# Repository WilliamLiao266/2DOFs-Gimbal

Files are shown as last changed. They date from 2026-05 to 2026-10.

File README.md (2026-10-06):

# 2DOFs Gimbal

基于 ESP32、SimpleFOC、双无刷电机和双 AS5600 磁编码器实现的两自由度云台。项目包含 Yaw / Pitch 双轴闭环控制固件、浏览器 PID 调参面板、结构模型以及硬件参考资料，可用于云台结构验证、FOC 调试和串口控制实验。

> 当前版本仍处于硬件调试阶段。上电前请先确认机械限位、供电电压、电机极对数与引脚配置，并确保急停或断电手段随时可用。

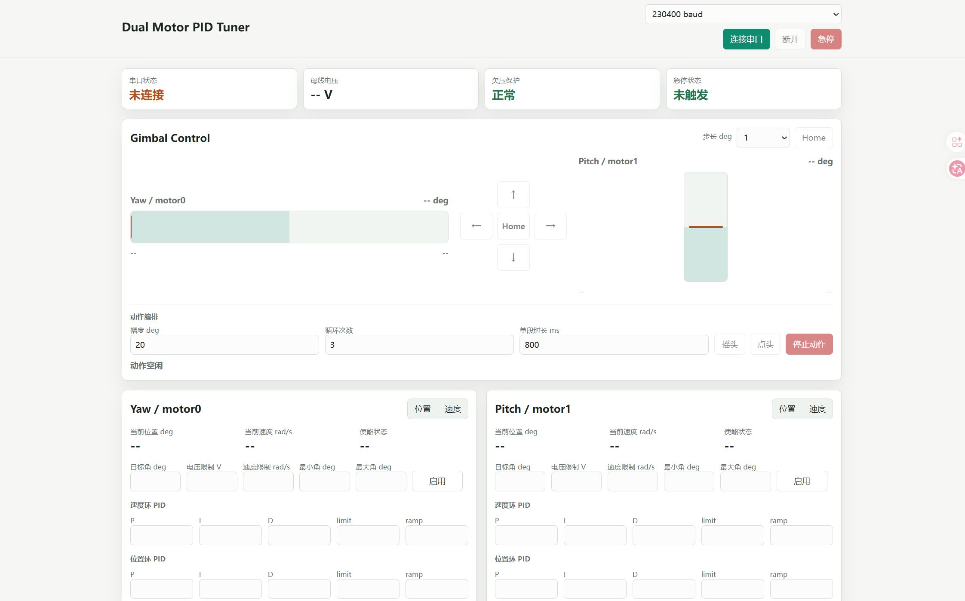
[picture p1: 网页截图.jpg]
双轴云台 Web 调试界面


## 功能特性

- 双轴 FOC：`motor0` 控制 Yaw，`motor1` 控制 Pitch
- 支持位置模式与速度模式，并可分别启用或关闭两个电机
- 在浏览器中通过 Web Serial 实时读取角度、速度、母线电压和运行状态
- 在线修改速度环 / 位置环 PID、输出限制、速度限制和角度范围
- 提供云台方向控制、步进点动、Home 和急停操作
- 具备 11.1 V 欠压保护、目标角限幅和串口急停
- 附带 SolidWorks / STEP 结构模型、电机尺寸图、驱动板及编码器资料

## 系统组成

| 模块 | 当前配置 |
| --- | --- |
| 主控 | LOLIN32 Lite（ESP32） |
| 控制框架 | Arduino + SimpleFOC 2.2.1 |
| 驱动方式 | 双路 3PWM 无刷电机驱动 |
| 位置反馈 | 2 × AS5600，通过两路独立 I²C 总线读取 |
| 控制轴 | Yaw（motor0）/ Pitch（motor1） |
| Yaw 电机 | GB1806 云台无刷电机 |
| Pitch 电机 | GB1105 云台无刷电机 |
| 调参方式 | Web Serial，230400 baud |
| 开发环境 | PlatformIO |

### 电机型号与购买链接

| 控制轴 | 电机型号 | 购买链接 |
| --- | --- | --- |
| Yaw / motor0 | **GB1806 云台无刷电机** | [淘宝购买](https://item.taobao.com/item.htm?id=809646293074) |
| Pitch / motor1 | **GB1105 云台无刷电机** | [淘宝购买](https://item.taobao.com/item.htm?id=650837545641) |

> 商品页面的价格、库存和可选配置可能发生变化，下单前请再次确认电机型号、绕组、编码器选项及安装尺寸。

### 当前固件引脚

| 功能 | motor0 / Yaw | motor1 / Pitch |
| --- | ---: | ---: |
| 电机极对数 | 7 | 6 |
| 3PWM | GPIO 32 / 33 / 25 | GPIO 26 / 27 / 14 |
| 驱动使能 | GPIO 12（两轴共用） | GPIO 12（两轴共用） |
| AS5600 SDA / SCL | GPIO 19 / 18 | GPIO 23 / 5 |

母线电压由 GPIO 13 采样，源码使用 `8.5` 倍分压换算，并在电压低于 `11.1 V` 时关闭电机。若硬件版本或分压电阻不同，请先修改 [`src/main.cpp`](./src/main.cpp) 中的配置。

## 快速开始

### 1. 准备环境

- 安装 [Visual Studio Code](https://code.visualstudio.com/) 与 [PlatformIO IDE](https://platformio.org/install/ide?install=vscode)，或单独安装 PlatformIO Core
- 使用支持 Web Serial 的桌面版 Chrome 或 Edge
- 接线并检查两个电机、两个 AS5600、驱动板、公共地和电源

### 2. 获取并编译固件

```bash
git clone https://github.com/WilliamLiao266/2DOFs-Gimbal.git
cd 2DOFs-Gimbal
pio run
```

### 3. 烧录与查看串口

连接 ESP32 后执行：

```bash
pio run --target upload
pio device monitor --baud 230400
```

如果自动识别不到串口，可在 `platformio.ini` 中设置 `upload_port` 和 `monitor_port`，或在命令中通过 `--upload-port` / `--port` 指定。

### 4. 打开 Web 调参面板

先退出串口监视器，避免串口被占用。然后在仓库根目录启动本地静态服务器：

```bash
python -m http.server 8000 --directory tools
```

使用 Chrome 或 Edge 打开 <http://localhost:8000/pid_tuner.html>，保持波特率为 `230400`，点击“连接串口”并选择 ESP32 对应端口。

> 浏览器串口和 PlatformIO 串口监视器不能同时占用同一个端口。调参时建议先设置较小的电压 / 速度限制，并逐轴启用。

## 默认控制参数

| 参数 | Yaw / motor0 | Pitch / motor1 |
| --- | ---: | ---: |
| 初始目标角 | 90° | 135° |
| 角度范围 | 0° ～ 180° | 85° ～ 165° |
| 电压限制 | 12.087 V | 12.070 V |
| 速度限制 | 5 rad/s | 60 rad/s |
| 速度环 P / I / D | 0.10 / 0.80 / 0 | 0.25 / 1.50 / 0 |
| 位置环 P / I / D | 3.0 / 0 / 0 | 4.0 / 0 / 0 |

以上是当前样机参数，不应直接视为其他电机或机械结构的安全参数。更换电机、供电、负载或减速结构后，请重新辨识方向、极对数、零位和 PID。

## 串口协议

命令使用英文逗号分隔，并以换行符结束。电机索引 `0` 为 Yaw，`1` 为 Pitch。

| 操作 | 示例 |
| --- | --- |
| 切换模式 | `MODE,0,angle` / `MODE,1,velocity` |
| 设置目标 | `TARGET,0,90` |
| 修改 PID | `PID,0,vel,P,0.1` |
| 修改电压限制 | `LIMIT,0,voltage,6` |
| 修改速度限制 | `LIMIT,1,velocity,10` |
| 修改角度范围 | `LIMIT,1,angleMin,85` |
| 启用 / 关闭电机 | `ENABLE,0,1` / `ENABLE,0,0` |
| 两轴急停 | `ESTOP` |

固件以 JSON Lines 形式返回遥测、确认和错误消息，Web 调参面板会自动解析这些数据。

## 调参记录

下图记录了两轮 PID 调试结果。第二轮加入了更明确的角度范围和两轴差异化参数，当前源码中的默认值以最新一轮结果为基础。

| 2026-05-21 初步调参 | 2026-05-22 迭代调参 |
| --- | --- |
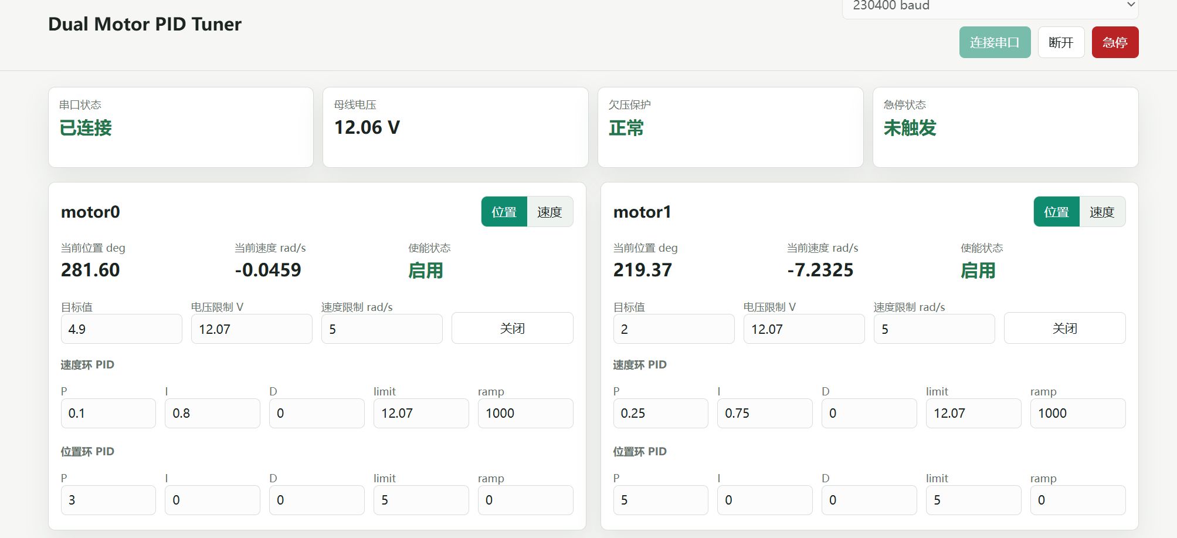
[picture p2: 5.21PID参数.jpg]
2026-05-21 PID 参数
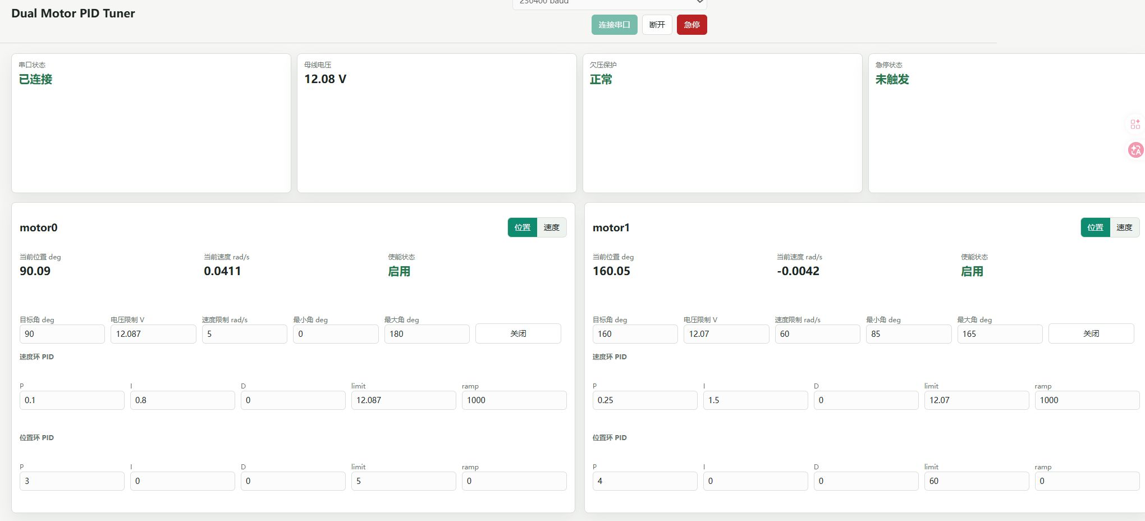
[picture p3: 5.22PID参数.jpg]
2026-05-22 PID 参数
|  |  |

## 项目结构

```text
.
├── src/main.cpp             # ESP32 双轴 FOC 固件与串口协议
├── tools/pid_tuner.html     # Web Serial 调参与云台控制面板
├── Motor_config/            # 电机资料图片
├── hardware_resource/       # 驱动板、编码器和安装尺寸资料
├── model/                   # SolidWorks 装配体、零件与 STEP 模型
├── platformio.ini           # PlatformIO 工程配置
├── 网页截图.jpg
├── 5.21PID参数.jpg
└── 5.22PID参数.jpg
```

## 安全提示

- 首次启动时拆除易碰撞负载，固定云台底座，并预留断电空间。
- `initFOC()` 会执行传感器与电机对齐；校准期间电机可能转动。
- GPIO 12 为两路驱动共用使能，请确认硬件连接与启动电平符合当前驱动板。
- 电压限制是控制器输出限制，不等同于电源或电机的额定安全电压。
- 调整角度上下限前先确认编码器方向和机械零位，防止撞击结构限位。
- 急停后需发送新的 `ENABLE` 命令才能恢复对应电机，请先排除故障原因。

## 许可证

本仓库目前尚未添加开源许可证。在许可证明确前，默认保留全部权利；如计划开放复用或接受外部贡献，请在发布时补充合适的 `LICENSE` 文件。

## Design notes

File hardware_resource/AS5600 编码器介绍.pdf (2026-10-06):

### AS5600 编码器板文档/AS5600 Encoder Board Document

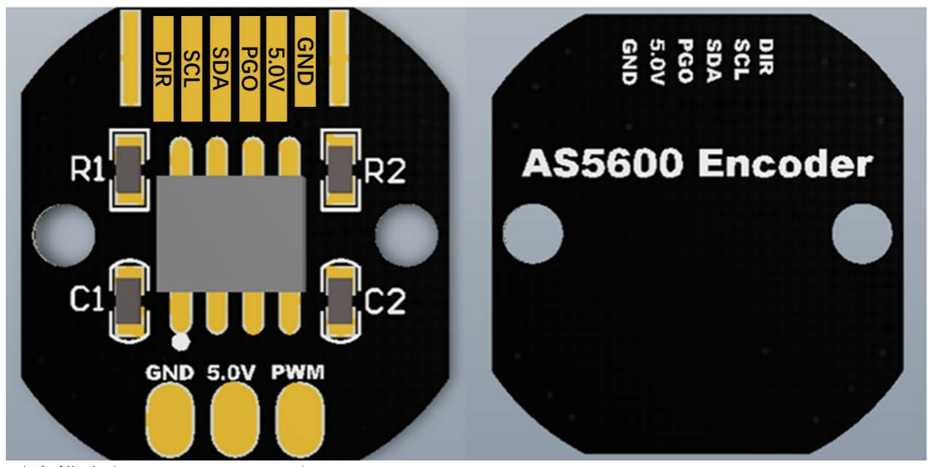
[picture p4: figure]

引脚描述(Pin Description)
名称(NAME) | 类型(TYPE) | 说明(Description)
GND | 电源(Supply) | 电源地(Ground)
5.0V | 电源(Supply) | 5V 直流电源(supply in 5V)
PWM | 输出(Output) | 460Hz PWM 输出(460Hz PWM Output)
PGO | 输入(Input） | 编程引脚(Program option)
SDA | 输入/输出(Input/Output) | I²C 数据引脚(I²C Data)
SCL | 输入(Input) | I²C 时钟引脚(I²C Clock)
DIR | 输入(Input) | 方向(Direction polarity)
尺寸(Size)

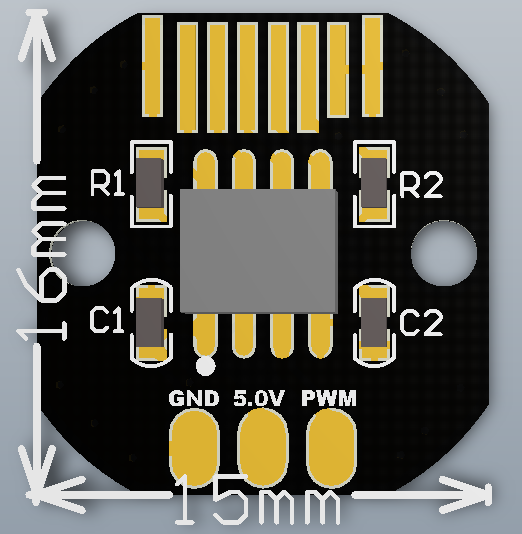
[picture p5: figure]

磁铁安装要求( Magnet
installation requirements)
- PCB 的尺寸为（15*16mm）;
- The Size of PCB is 15*16mm;
- PCB 四角的圆弧为半径 9mm 的同心圆；
- The circular arc of the PCB four angle is the concentric circle of the radius 9mm；
- 定位孔的直径为 2.2mm，并且两个定位孔
之间的距离为 12mm；
- The diameter of the positioning hole is 2.2mm, and the distance between the two positioning holes is 12mm.
- 以上与实际尺寸有细微偏差(There is a slight deviation in the actual size)

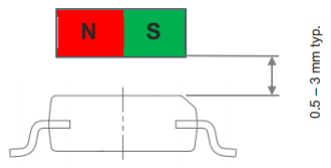
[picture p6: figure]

- 根据磁铁，磁铁与编码器表面距离为 0.5-3mm；
- The typical airgap is between 0.5 mm and 3 mm, and it depends；

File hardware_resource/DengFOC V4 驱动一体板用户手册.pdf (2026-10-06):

# DengFOC V4

# 驱动一体板用户手册

## 1 产品介绍

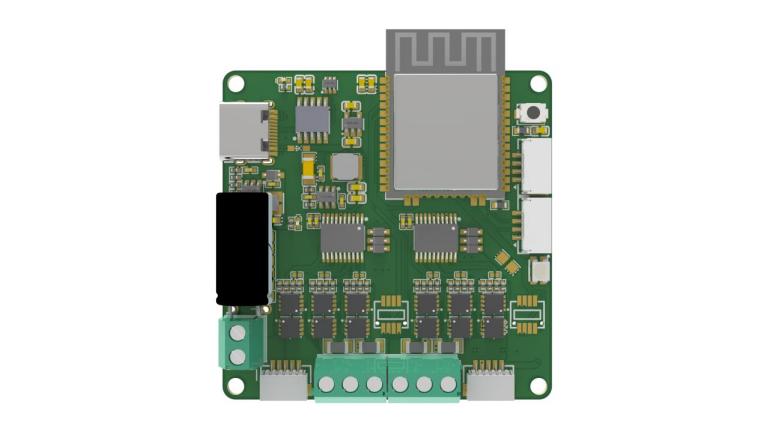
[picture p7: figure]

DengFOC-V4 是一款由灯哥开源推出的控驱一体的双路 FOC 驱动器，该驱 动器 支持 ABI/IIC/UVW/SPI 等几乎所有常用制式编码器的信息输入；低成本实 现了真正的 无刷电机的 FOC 控制；是 DIY 低成本无刷机器人、平衡车、无刷云 台，以及学习基 于电流环无刷电机 FOC 控制的不二选择。

在目前发布的升级版本 V4 中，我们增加了可选配的 拔插式电流传感器，相 比老 版本 V3P，体积更小！集成了主控模组 ESP32-WROOM-32U，实现控制驱 动一体 化。同样支持云台电机和部分航模电机！

## 1.1 基本规格参数

规格 | 参数
输入电压 | 12V~24V
最大持续电流 | 12A
电流传感器(选配) | INA240
电流检测采样电阻 | 10mR
电流检测电流范围 | ±33A（1mR 采样电阻下）
编码器支持类型 | ABI、IIC、UVW、SPI、SSI
通讯方式 | 串口（Type-C）
扩展端子规格 | GH1.25-4P *2
产品尺寸 | 50*50mm（板载天线另算）
净重 | 19.2g

## 1.2 硬件功能引脚图

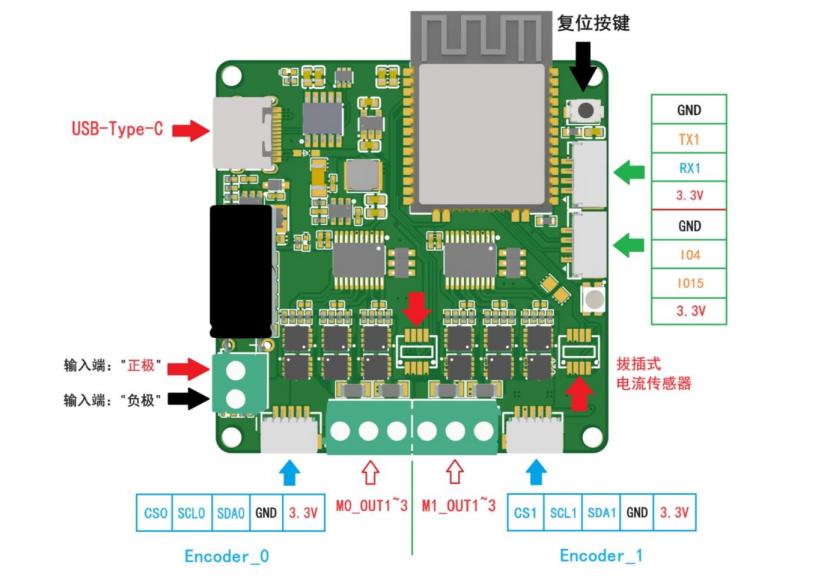
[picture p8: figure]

- 两个编码器接口（SH1.0 规格），支持 IIC、SSI 和 ABI 等通信方式的编码 器， 例如 AS5600 和 AS5047P 等
- 一组串口接口以及一组自定义的 IO 口（GH1.25 规格）
- 两个拔插式电流传感器
引脚 | 说明
TX1 | 串口 1 发送引脚
RX1 | 串口 1 接受引脚
GND | 信号地
3.3V | 3.3V 对外供电
M0_OUT1~3 | M0 电机三相输出，不分三相线序
M1_OUT1~3 | M1 电机三相输出，不分三相线序

SCL0 和 SCL1 | IIC 时钟线
SDA0 和 SDA1 | IIC 数据线
CS0 和 CS1 | SPI 通讯片选引脚（使用 IIC 通信时只连接但不启用）
IO4 和 IO15 | 引出的引脚，可随意分配使用

## 1.3 机械尺寸

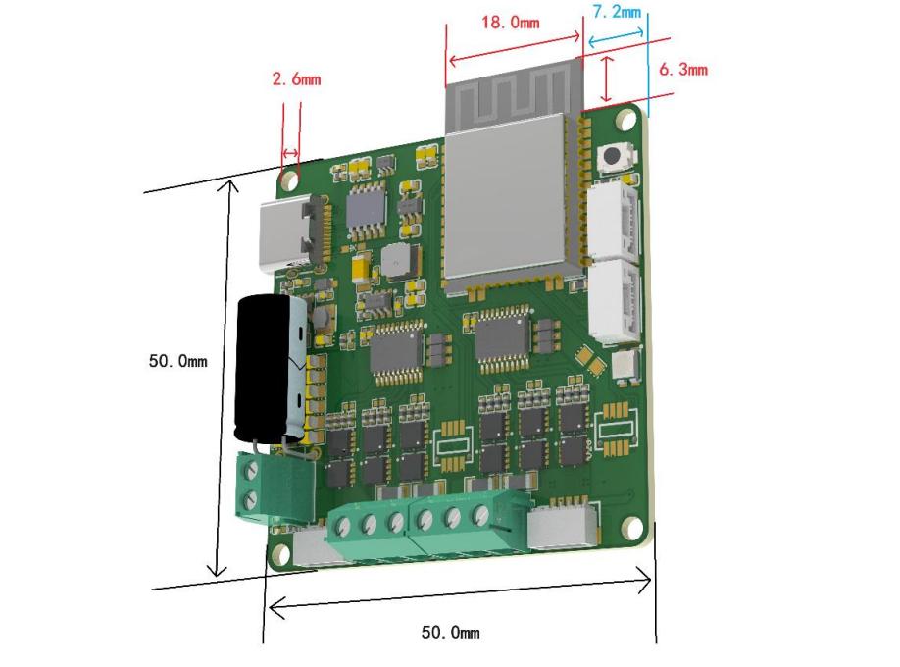
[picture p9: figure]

## 2 使用指南

## 2.1 硬件准备

- 装有 Windows 系统的 PC
- DengFOC-V4 驱动板
- Type-C 口的 USB 数据线
- 12V-24V 供电电源

- 一个或两个云台电机
- 一个或两个编码器，推荐使用 AS5600

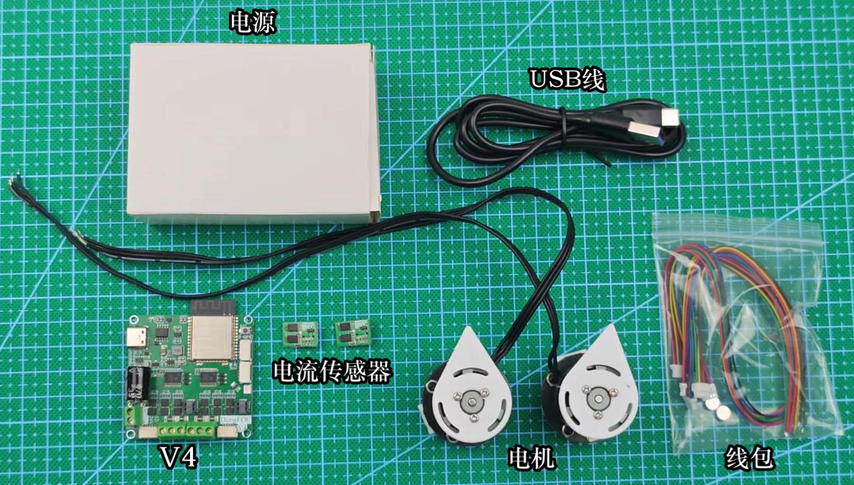
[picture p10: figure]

电机与编码器的安装参考 "v4 到手资料" 文件夹的 2208 电机安装图解.pdf

电机与 v3p 驱动板的安装参考 "v4 到手资料" 文件夹的 V4 接线安装.mp4

## 2.2 软件配置

ESP32 开发平台可选 Arduino IDE 平台 或 PlatformIO 平台 (VSCode)

### Arduino IDE 平台 - Arduino IDE: 官网最新版或较新版本

- ESP32 版本: 2.0.4 或者 2.0.10

### - SimpleFOC 版本: 2.2.1 （推荐）PlatformIO 平台 (VSCode) • PlatformIO 版本: 6.6.0

### - SimpleFOC 版本: 2.2.1

| 具体开发环境安装与例程代码烧录请查看"v4 到手资料"文件夹中对应的视频教学

# 2.3 SimpleFOC 例程

我们为 DengFOC V3 Plus 提供了丰富的例程, 存放于群文件的例程资料文件夹里

1 号例程 | 双电机开环速度控制
2 号例程 | 双电机开环位置控制
3 号例程 | IIC 双编码器测试(AS5600)
4 号例程 | ABI 双编码器测试(AS5047P)
5 号例程 | SPI 编码器测试(AS5047P)
6 号例程 | 霍尔编码器测试_5 线
7 号例程 | 双霍尔电机闭环测试_5 线
8 号例程 | 双电机_电压闭环速度控制
9 号例程 | 双电机_电压闭环位置控制
10 号例程 | 双电机_电压闭环位置力矩互控
11 号例程 | 双电机_电流闭环速度控制
12 号例程 | 双电机_电流闭环位置控制
13 号例程 | 双电机_电流闭环位置力矩互控
14 号例程 | 双电机完整 FOC 力矩控制
15 号例程 | 双电机在线电流检测测试
16 号例程 | SimpleFOC Studio 快速调节_PID-驱动板端例程—M0 端
17 号例程 | SimpleFOC Studio 快速调节_PID-驱动板端例程—M1 端

18 号例程 | SimpleFOC Studio_M0 端_无线蓝牙控制
19 号例程 | 灯哥开源机器狗专用程序_通过串口控制此 FOC 驱动板_
20 号例程 | 一个电机作为旋钮_另外一个电机输出速度
21 号例程 | 重力前馈例程

# 2.4 DengFOC 手把手教学 FOC 例程

B 站 灯哥手把手教你写 FOC 算法 系列课程 合集链接 灯哥开源的个人空间-灯哥开 源个人主页-哔哩哔哩视频 (https://space.bilibili.com/493192058/lists/1104775?type=season)

《灯哥手把手教你写 FOC 算法》 精品课程合集 对应 课程代码， 存放于群文件的 例程资料文件夹里

1 | 第五章 a+b 开环速度 FOC 代码
2 | 第六章 a+b 闭环位置 FOC 代码-DengFOC 库 v0.1
3 | 第七章 a+b 闭环速度 FOC 代码-DengFOC 库 v0.2
4 | 第八章 a+b 电流力矩闭环
5 | 第九章 a+b 位置闭环，速度闭环升级版（加上电流环）
6 | 第十课 a+b 双电机闭环 FOC 代码
7 | 第十一课 a+b SVPWM 的算法实现思路和框架

## 2.5 V4 进阶版课程 例程

V4 的进阶视频需要联系淘宝客服获取！！！

课程对应的例程在群文件的 ESP 无感 FOC 历程资料

1 | 例程 1：无感滑膜_电压力矩
2 | 例程 2：无感滑膜_电流力矩
3 | 例程 3：无感滑膜_速度控制
4 | 例程 4：无感滑膜_完整控制例程
5 | 课程 4：SMO 滑模观测器
6 | 课程 5：PLL 锁相环
7 | 课程 6：VF 启动
8 | 课程 7：力矩控制
9 | 课程 8：速度控制
10 | 课程 9：simulink 模型

## 3 常见问题及解决方法

如遇到开发环境安装失败，例程无法烧录，电机无法正常运行等情况可查看 “例程 常见问题与解决办法合集"文件夹，可快速排查错误

# 4 DengFOC 电机辨识工具箱

电机参数设置是使用 DengFOC 首先需要进行的必做项，对于已有参数的电机，这一 步很好完成，如 DengFOC 2208 电机的餐宿可以在淘宝详情页中获取，若使用没有参 数说明表格的电机，需要针对没有参数说明表格的电机查阅相当多的资料才能顺利用 起来。
DengFOC 电机辨识工具箱由灯哥团队倾力开发，配合 DengFOC V3P 升级版的硬 件，可以在几分钟内快速辨识电机的极对数和 KV 值（软件可以在售后群下载得 到）。软件主界面如下所示：

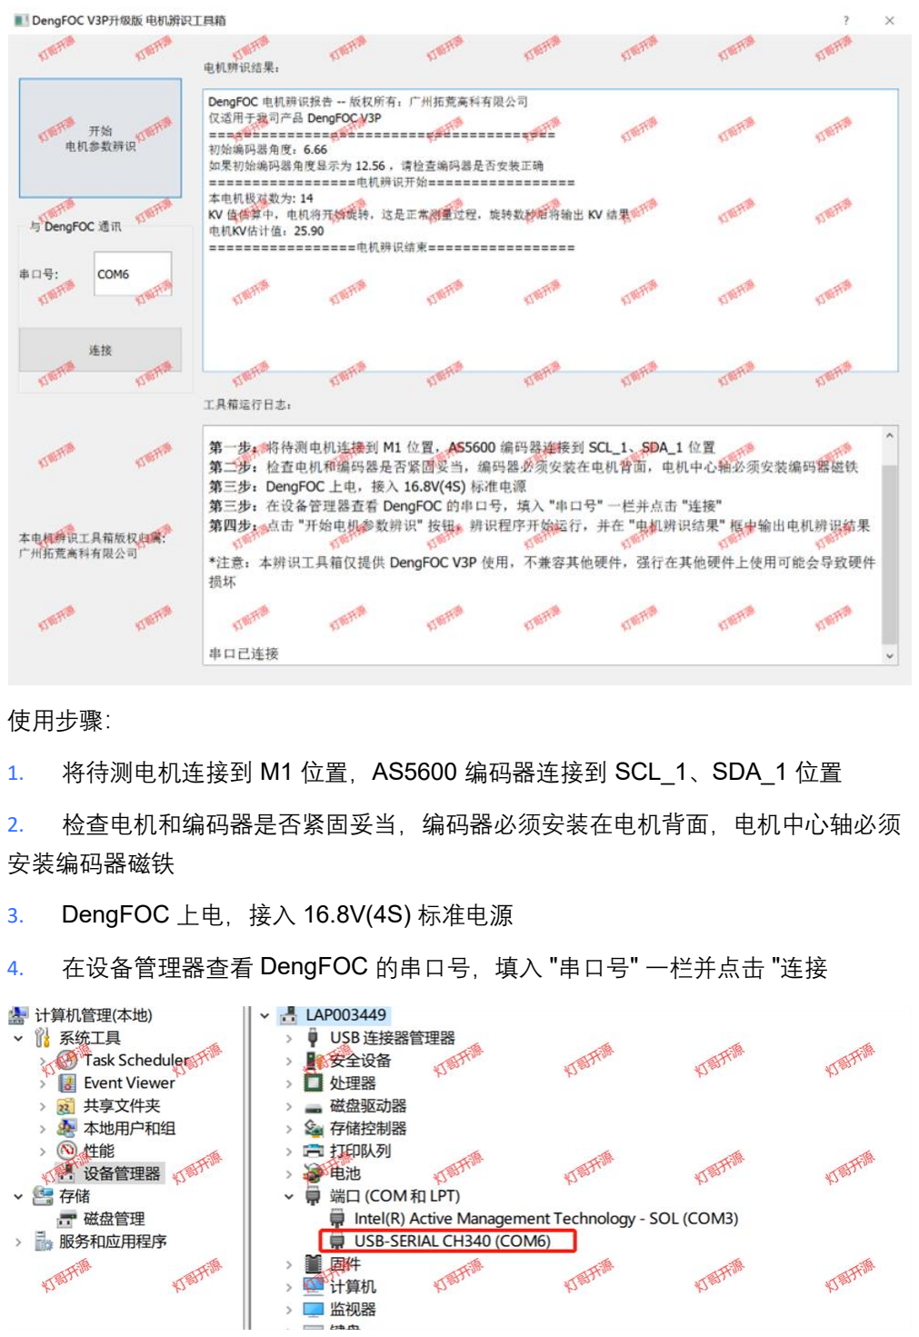
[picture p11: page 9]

使用步骤：
1. 将待测电机连接到 M1 位置，AS5600 编码器连接到 SCL_1、SDA_1 位置
2. 检查电机和编码器是否紧固妥当，编码器必须安装在电机背面，电机中心轴必须 安装编码器磁铁
3. DengFOC 上电，接入 16.8V(4S) 标准电源
4. 在设备管理器查看 DengFOC 的串口号，填入 "串口号" 一栏并点击 "连接

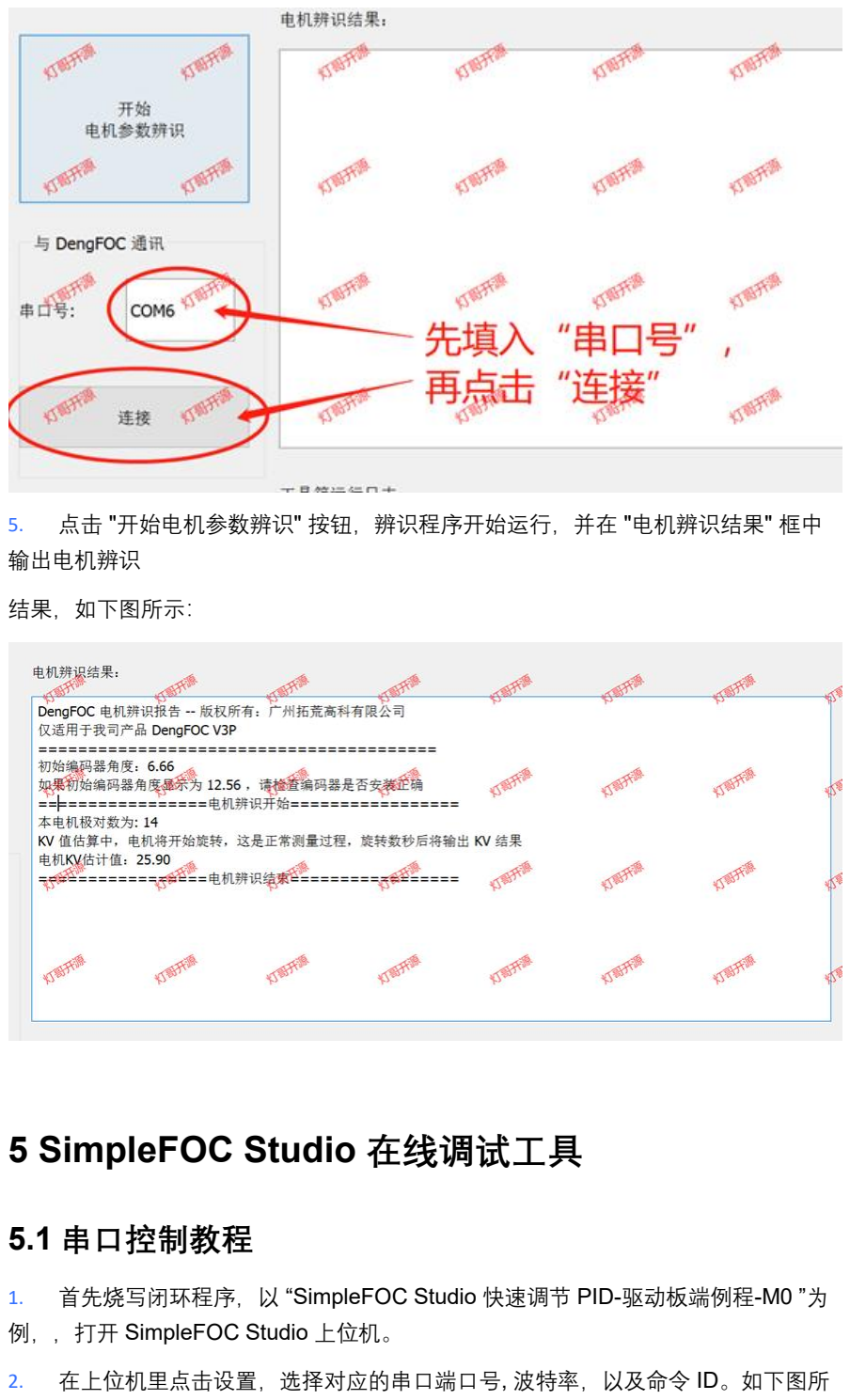
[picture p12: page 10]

5. 点击 "开始电机参数辨识" 按钮，辨识程序开始运行，并在 "电机辨识结果" 框中 输出电机辨识

结果，如下图所示：

# 5 SimpleFOC Studio 在线调试工具

## 5.1 串口控制教程

1. 首先烧写闭环程序，以 “SimpleFOC Studio 快速调节 PID-驱动板端例程-M0 ”为 例，，打开 SimpleFOC Studio 上位机。
2. 在上位机里点击设置，选择对应的串口端口号, 波特率，以及命令 ID。如下图所

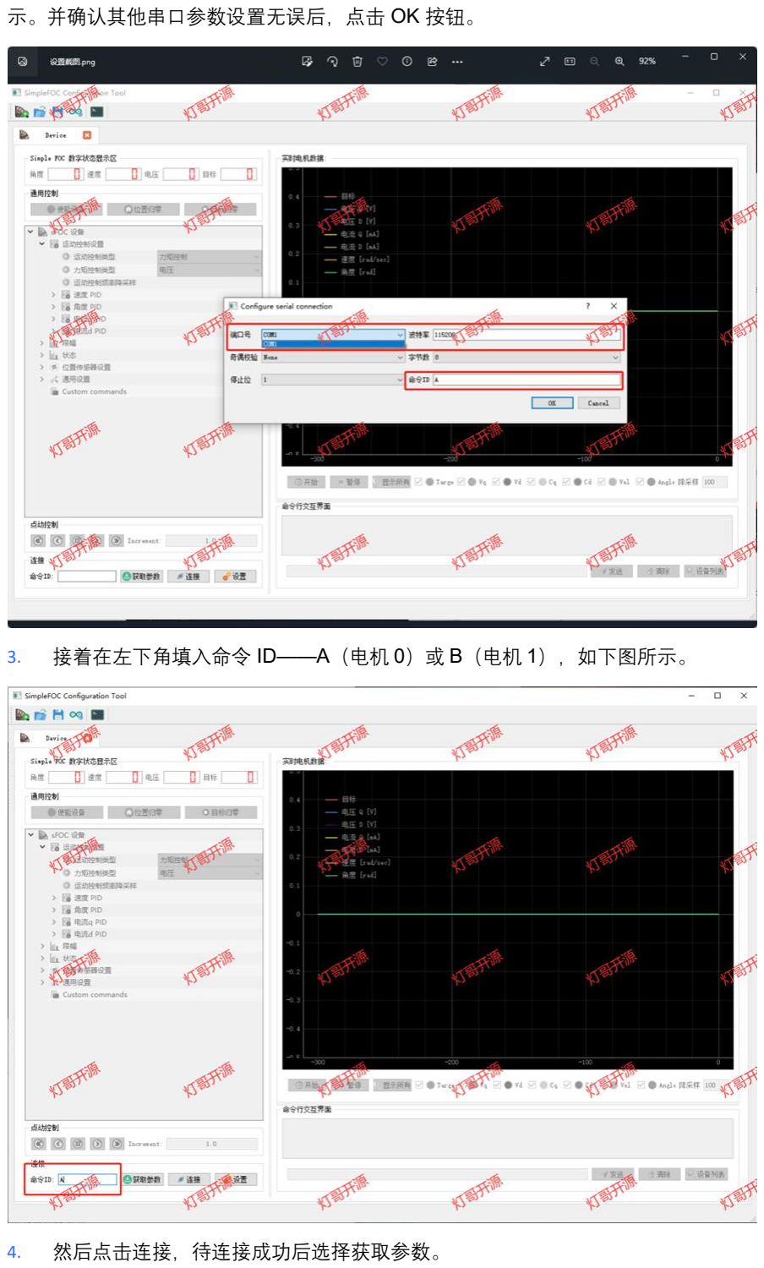
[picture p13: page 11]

示。并确认其他串口参数设置无误后，点击 OK 按钮。

3. 接着在左下角填入命令 ID——A（电机 0）或 B（电机 1），如下图所示。
4. 然后点击连接，待连接成功后选择获取参数。

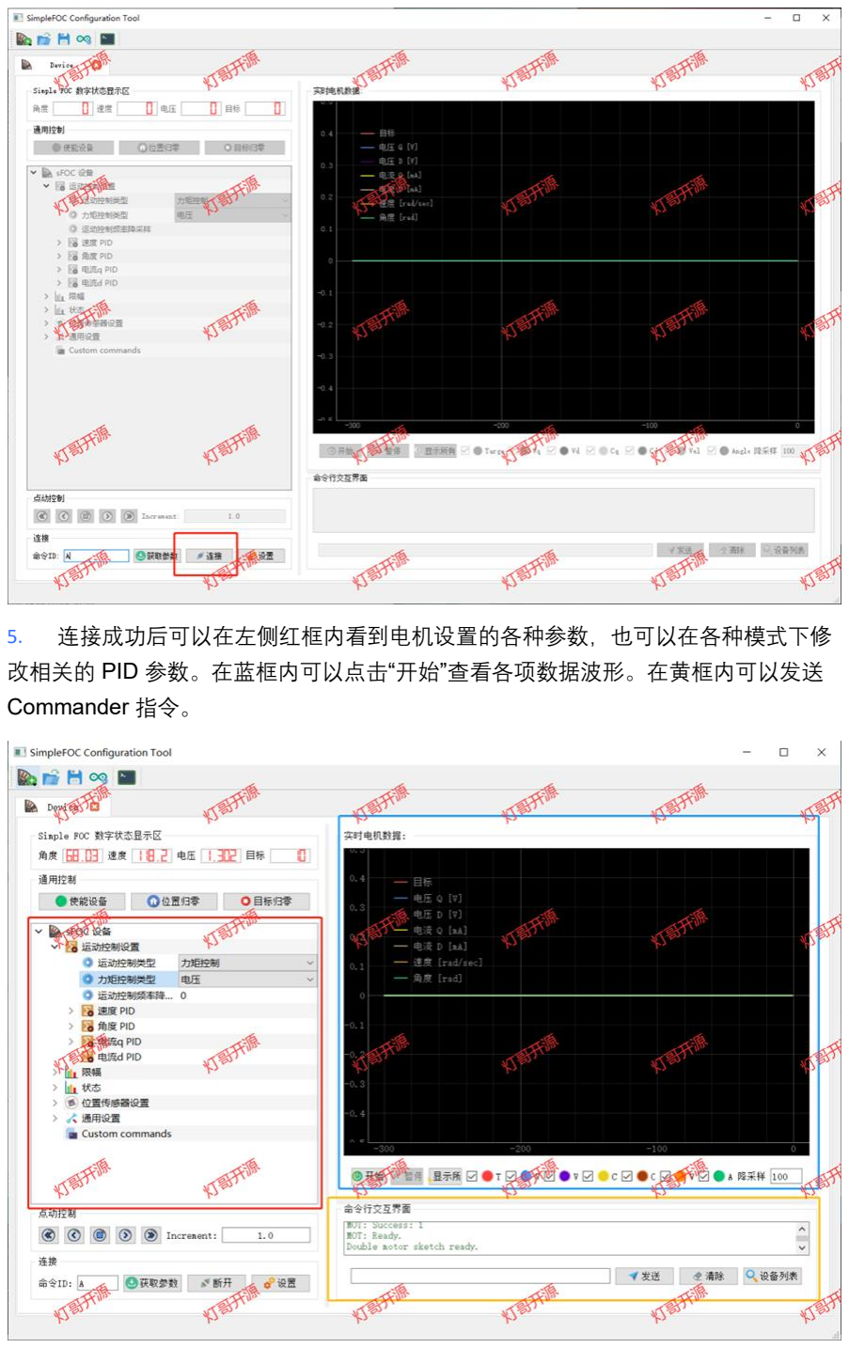
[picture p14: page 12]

5. 连接成功后可以在左侧红框内看到电机设置的各种参数，也可以在各种模式下修 改相关的 PID 参数。在蓝框内可以点击“开始”查看各项数据波形。在黄框内可以发送 Commander 指令。

# 5.2 Commander 指令举例

- 如需切换电机控制模式，可以在下方命令行输入指令进行切换，输入 AC0 为力 矩控制模式，AC1 为速度模式，AC2 为角度模式。其中第一个字母 A 为命令 ID，若 命令 ID 填入 B，则用 BC0 等命令切换控制模式。
- 选择完控制模式后，输入 A+目标控制值，例如在速度模式下输入 A2，则电机将 以 2rad/s 的速度旋转。

详情视频教学 点击该链接转跳 B 站视频【教程】【SimpleFOC Studio 图形化调试 软件的使用】DIY 不足百元的无刷电机闭环驱动--SimpleFOC(5)_哔哩哔哩_bilibili (https://www.bilibili.com/video/BV1cj411M7Xu/?spm_id_from=333.1387.homepage.video_card.click)

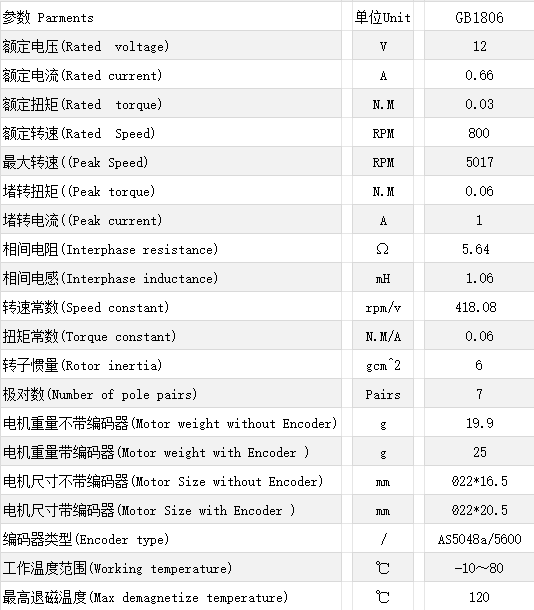
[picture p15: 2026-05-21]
Motor_config/GB1806.png

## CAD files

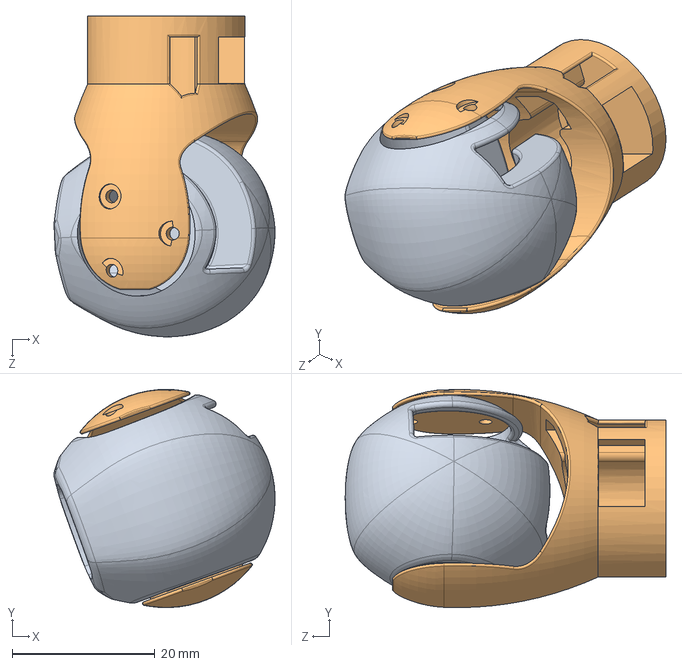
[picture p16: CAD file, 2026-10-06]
model/装配体.SLDASM
30.9 x 30.5 x 44.8 mm
头部连接件
腰部连接件

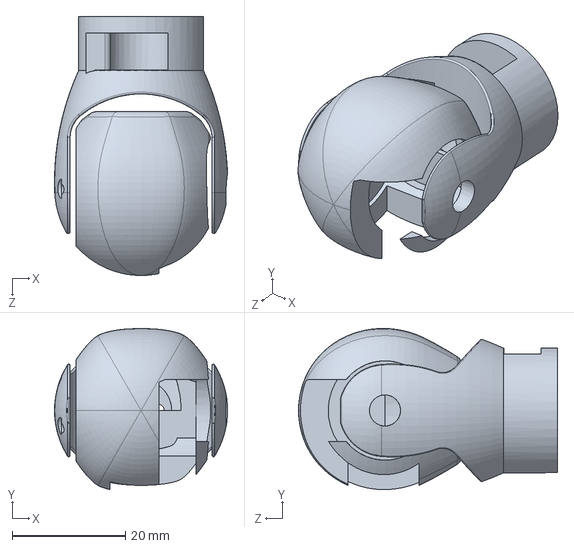
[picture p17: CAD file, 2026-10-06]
model/主体实体.SLDPRT
30.5 x 28.4 x 45.6 mm

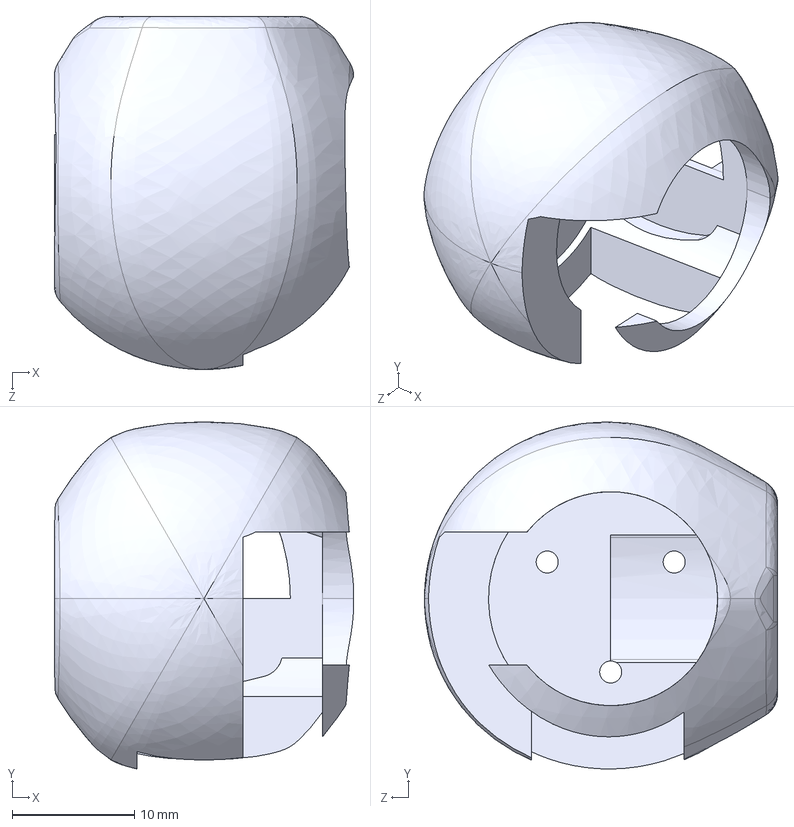
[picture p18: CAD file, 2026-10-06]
model/头部连接件迭代.STEP
24.5 x 28.4 x 28.9 mm

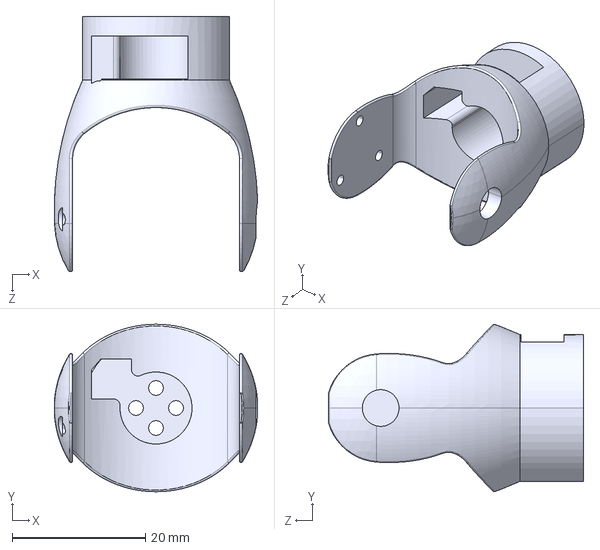
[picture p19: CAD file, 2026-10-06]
model/腰部连接件迭代.STEP
30.5 x 25.1 x 38.2 mm

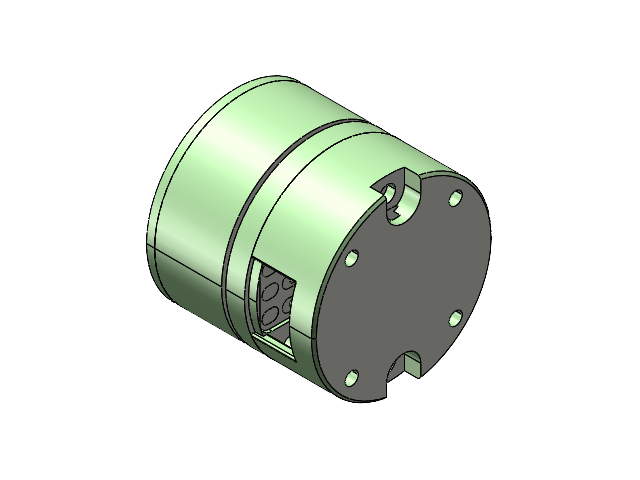
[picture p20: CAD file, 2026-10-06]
model/GB1806带后盖.SLDASM
1806____.STEP
1806____-0.STEP
1806____-1.STEP
2205______.STEP
2205____-____________.STEP
1806____-2.STEP

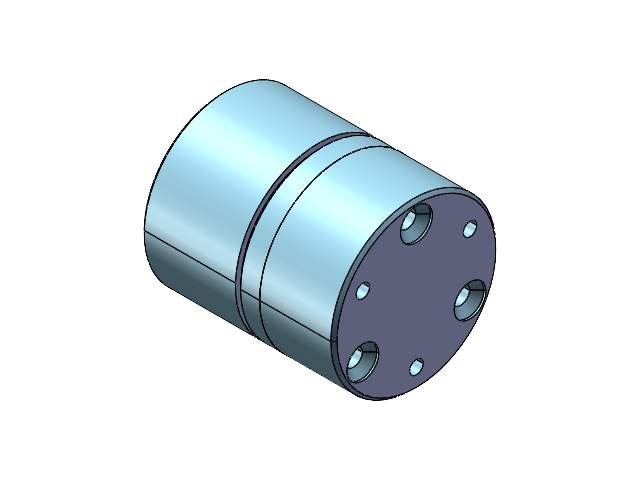
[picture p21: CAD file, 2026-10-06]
model/GB1105带后盖.SLDASM
1305____.STEP
1305____-0.STEP
1305__.STEP
1305____-15-40-20.STEP x 2
1305______.STEP
112_____6.STEP
1305____-1.STEP
1305____________.STEP
6x2.5____.STEP
1305____-2.STEP

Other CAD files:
model/头部连接件迭代.SLDPRT
model/腰部连接件迭代.SLDPRT

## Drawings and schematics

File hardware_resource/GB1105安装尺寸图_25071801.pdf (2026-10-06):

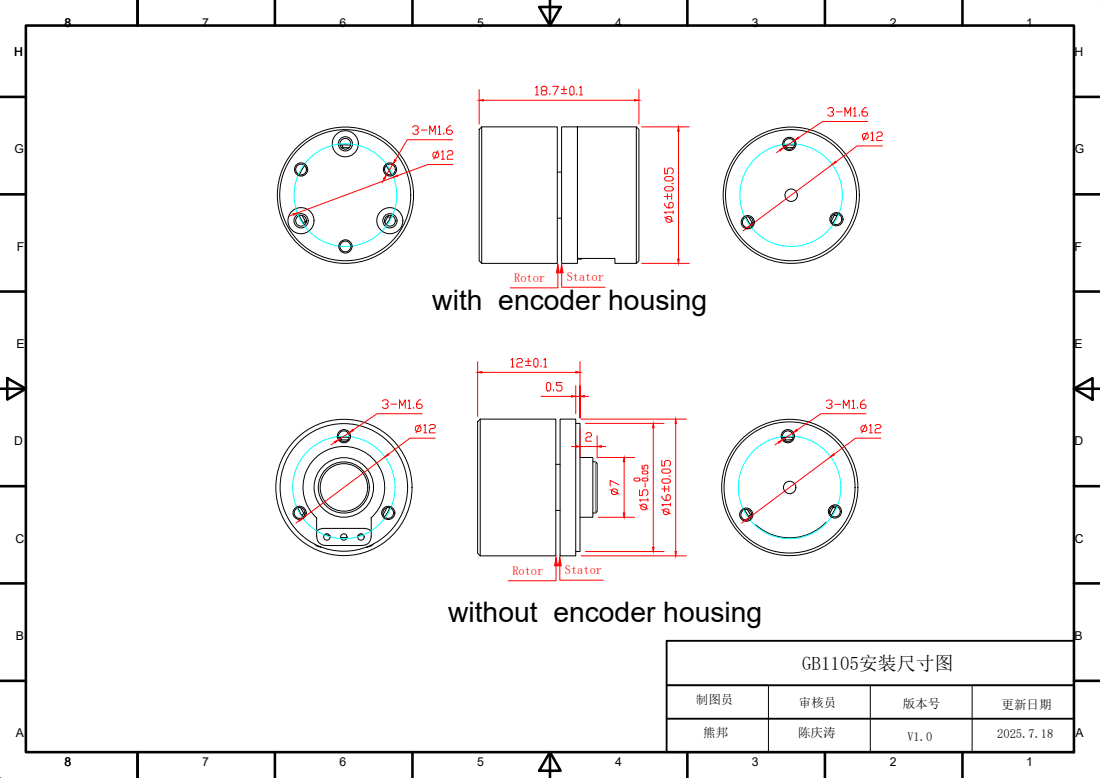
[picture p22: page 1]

with encoder housing

without encoder housing

制图员 审核员 | 版本号 更新日期

熊邦 陈庆涛 | 2025.7.18 V1.0

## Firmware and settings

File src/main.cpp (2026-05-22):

/**
 * Dual motor SimpleFOC PID tuner firmware.
 *
 * Serial protocol, newline terminated:
 *   MODE,0,angle
 *   TARGET,1,90
 *   PID,0,vel,P,0.015
 *   PID,1,angle,ramp,1000
 *   LIMIT,0,voltage,12
 *   LIMIT,1,velocity,20
 *   LIMIT,0,angleMin,10
 *   LIMIT,0,angleMax,170
 *   ENABLE,0,1
 *   ESTOP
 */

#include <SimpleFOC.h>
#include <ctype.h>
#include <math.h>
#include <stdlib.h>
#include <string.h>

MagneticSensorI2C sensor = MagneticSensorI2C(AS5600_I2C);
MagneticSensorI2C sensor1 = MagneticSensorI2C(AS5600_I2C);
TwoWire I2Cone = TwoWire(0);
TwoWire I2Ctwo = TwoWire(1);

// Motor parameters
BLDCMotor motor = BLDCMotor(7);
BLDCDriver3PWM driver = BLDCDriver3PWM(32, 33, 25, 12);

BLDCMotor motor1 = BLDCMotor(6);
BLDCDriver3PWM driver1 = BLDCDriver3PWM(26, 27, 14, 12);

#define UNDERVOLTAGE_THRES 11.1f
#define SERIAL_BAUD 230400
#define TELEMETRY_PERIOD_MS 50
#define BOARD_CHECK_PERIOD_MS 1000
#define COMMAND_BUFFER_SIZE 96
#define ANGLE_LIMIT_MIN_DEG 0.0f
#define ANGLE_LIMIT_MAX_DEG 360.0f

struct AxisConfig
{
  const char *name;
  float target_angle_deg;
  float angle_min_deg;
  float angle_max_deg;
  float voltage_limit;
  float velocity_limit;
  float velocity_p;
  float velocity_i;
  float velocity_d;
  float velocity_ramp;
  float angle_p;
  float angle_i;
  float angle_d;
  float angle_ramp;
};

const AxisConfig axis_configs[] = {
    {"Yaw", 90.0f, 0.0f, 180.0f, 12.087f, 5.0f, 0.10f, 0.80f, 0.0f, 1000.0f, 3.0f, 0.0f, 0.0f, 0.0f},
    {"Pitch", 135.0f, 85.0f, 165.0f, 12.070f, 60.0f, 0.25f, 1.50f, 0.0f, 1000.0f, 4.0f, 0.0f, 0.0f, 0.0f}};

BLDCMotor *motors[] = {&motor, &motor1};
float target_angle_deg[] = {axis_configs[0].target_angle_deg, axis_configs[1].target_angle_deg};
float target_velocity_rad_s[] = {0.0f, 0.0f};
float angle_min_deg[] = {axis_configs[0].angle_min_deg, axis_configs[1].angle_min_deg};
float angle_max_deg[] = {axis_configs[0].angle_max_deg, axis_configs[1].angle_max_deg};
bool requested_enable[] = {true, true};

uint32_t prev_board_check_millis = 0;
uint32_t prev_telemetry_millis = 0;
bool flag_under_voltage = false;
bool emergency_stop = false;
char command_buffer[COMMAND_BUFFER_SIZE];
uint8_t command_length = 0;

void board_check();
float get_vin_Volt();
void board_init();
void handle_serial();
void handle_command(char *line);
void send_telemetry();
void send_ack(const char *cmd);
void send_error(const char *cmd, const char *message);
void apply_enable_state();
BLDCMotor *select_motor(const char *token, int *motor_index);
bool equals_ignore_case(const char *left, const char *right);
bool parse_float(const char *token, float *value);
bool parse_bool(const char *token, bool *value);
const char *mode_name(BLDCMotor *selected_motor);
void print_pid(PIDController &pid);
void print_motor_json(int index);
void apply_axis_config(int index);
float angle_rad_to_degrees_0_360(float angle_rad);
float degrees_to_radians(float angle_deg);
float clamp_float(float value, float minimum, float maximum);
float clamp_angle_limit_degrees(float angle_deg);
bool angle_within_limits(float angle_deg, int motor_index);
float circular_distance_degrees(float left, float right);
float clamp_angle_target_degrees(float angle_deg, int motor_index);
float motion_target_for_motor(int motor_index);
float telemetry_target_for_motor(int motor_index);

void setup()
{
  Serial.begin(SERIAL_BAUD);
  board_init();

  I2Cone.begin(19, 18, 400000UL); // AS5600_M0
  I2Ctwo.begin(23, 5, 400000UL);  // AS5600_M1
  sensor.init(&I2Cone);
  sensor1.init(&I2Ctwo);

  motor.linkSensor(&sensor);
  motor1.linkSensor(&sensor1);

  driver.voltage_power_supply = get_vin_Volt();
  driver.init();

  driver1.voltage_power_supply = get_vin_Volt();
  driver1.init();

  motor.linkDriver(&driver);
  motor1.linkDriver(&driver1);

  motor.foc_modulation = FOCModulationType::SpaceVectorPWM;
  motor1.foc_modulation = FOCModulationType::SpaceVectorPWM;

  motor.controller = MotionControlType::angle;
  motor1.controller = MotionControlType::angle;

  motor.LPF_velocity.Tf = 0.01f;
  motor1.LPF_velocity.Tf = 0.01f;

  apply_axis_config(0);
  apply_axis_config(1);

  motor.init();
  motor1.init();

  motor.initFOC();
  motor1.initFOC();
  apply_enable_state();

  Serial.println(F("{\"type\":\"ready\",\"message\":\"dual_pid_tuner\"}"));
}

void loop()
{
  motor.loopFOC();
  motor1.loopFOC();

  motor.move(motion_target_for_motor(0));
  motor1.move(motion_target_for_motor(1));

  board_check();
  handle_serial();
  send_telemetry();
}

void board_init()
{
  pinMode(32, INPUT_PULLUP);
  pinMode(33, INPUT_PULLUP);
  pinMode(25, INPUT_PULLUP);
  pinMode(26, INPUT_PULLUP);
  pinMode(27, INPUT_PULLUP);
  pinMode(14, INPUT_PULLUP);

  analogReadResolution(12); // 12bit

  float VIN_Volt = get_vin_Volt();
  while (VIN_Volt <= UNDERVOLTAGE_THRES)
  {
    VIN_Volt = get_vin_Volt();
    delay(100);
    Serial.printf("{\"type\":\"wait_power\",\"vin\":%.2f}\n", VIN_Volt);
  }
  Serial.printf("{\"type\":\"calibrating\",\"vin\":%.2f}\n", VIN_Volt);
}

float get_vin_Volt()
{
  return analogReadMilliVolts(13) * 8.5f / 1000.0f;
}

void board_check()
{
  uint32_t curr_millis = millis();

  if (curr_millis - prev_board_check_millis < BOARD_CHECK_PERIOD_MS)
  {
    return;
  }

  float vin_Volt = get_vin_Volt();
  bool now_under_voltage = vin_Volt < UNDERVOLTAGE_THRES;

  if (now_under_voltage)
  {
    uint8_t count = 5;
    while (count--)
    {
      vin_Volt = get_vin_Volt();
      if (vin_Volt > UNDERVOLTAGE_THRES)
      {
        now_under_voltage = false;
        break;
      }
    }
  }

  flag_under_voltage = now_under_voltage;
  apply_enable_state();
  prev_board_check_millis = curr_millis;
}

void apply_enable_state()
{
  for (uint8_t i = 0; i < 2; i++)
  {
    if (flag_under_voltage || emergency_stop || !requested_enable[i])
    {
      motors[i]->disable();
    }
    else if (!motors[i]->enabled)
    {
      motors[i]->enable();
    }
  }
}

void handle_serial()
{
  while (Serial.available())
  {
    char ch = (char)Serial.read();
    if (ch == '\n' || ch == '\r')
    {
      if (command_length > 0)
      {
        command_buffer[command_length] = '\0';
        handle_command(command_buffer);
        command_length = 0;
      }
      continue;
    }

    if (command_length < COMMAND_BUFFER_SIZE - 1)
    {
      command_buffer[command_length++] = ch;
    }
    else
    {
      command_length = 0;
      send_error("BUFFER", "command too long");
    }
  }
}

void handle_command(char *line)
{
  char original[COMMAND_BUFFER_SIZE];
  strncpy(original, line, sizeof(original));
  original[sizeof(original) - 1] = '\0';

  char *cmd = strtok(line, ",");
  if (!cmd)
  {
    send_error("EMPTY", "missing command");
    return;
  }

  if (equals_ignore_case(cmd, "ESTOP"))
  {
    emergency_stop = true;
    requested_enable[0] = false;
    requested_enable[1] = false;
    apply_enable_state();
    send_ack(original);
    return;
  }

  char *motor_token = strtok(NULL, ",");
  int motor_index = -1;
  BLDCMotor *selected_motor = select_motor(motor_token, &motor_index);
  if (!selected_motor)
  {
    send_error(original, "invalid motor index");
    return;
  }

  if (equals_ignore_case(cmd, "MODE"))
  {
    char *mode = strtok(NULL, ",");
    if (equals_ignore_case(mode, "angle") || equals_ignore_case(mode, "position"))
    {
      selected_motor->controller = MotionControlType::angle;
      target_angle_deg[motor_index] = clamp_angle_target_degrees(target_angle_deg[motor_index], motor_index);
      send_ack(original);
    }
    else if (equals_ignore_case(mode, "velocity") || equals_ignore_case(mode, "speed"))
    {
      selected_motor->controller = MotionControlType::velocity;
      send_ack(original);
    }
    else
    {
      send_error(original, "invalid mode");
    }
    return;
  }

  if (equals_ignore_case(cmd, "TARGET"))
  {
    float value = 0.0f;
    if (!parse_float(strtok(NULL, ","), &value))
    {
      send_error(original, "invalid target");
      return;
    }

    if (selected_motor->controller == MotionControlType::angle)
    {
      target_angle_deg[motor_index] = clamp_angle_target_degrees(value, motor_index);
    }
    else if (selected_motor->controller == MotionControlType::velocity)
    {
      target_velocity_rad_s[motor_index] = value;
    }
    else
    {
      send_error(original, "unsupported target mode");
      return;
    }

    send_ack(original);
    return;
  }

  if (equals_ignore_case(cmd, "PID"))
  {
    char *loop = strtok(NULL, ",");
    char *param = strtok(NULL, ",");
    float value = 0.0f;
    if (!loop || !param || !parse_float(strtok(NULL, ","), &value))
    {
      send_error(original, "invalid pid command");
      return;
    }

    PIDController *pid = nullptr;
    if (equals_ignore_case(loop, "vel") || equals_ignore_case(loop, "velocity") || equals_ignore_case(loop, "speed"))
    {
      pid = &selected_motor->PID_velocity;
    }
    else if (equals_ignore_case(loop, "angle") || equals_ignore_case(loop, "position") || equals_ignore_case(loop, "pos"))
    {
      pid = &selected_motor->P_angle;
    }
    else
    {
      send_error(original, "invalid pid loop");
      return;
    }

    if (equals_ignore_case(param, "P"))
    {
      pid->P = value;
    }
    else if (equals_ignore_case(param, "I"))
    {
      pid->I = value;
    }
    else if (equals_ignore_case(param, "D"))
    {
      pid->D = value;
    }
    else if (equals_ignore_case(param, "limit"))
    {
      pid->limit = value;
      if (pid == &selected_motor->P_angle)
      {
        selected_motor->velocity_limit = value;
      }
    }
    else if (equals_ignore_case(param, "ramp") || equals_ignore_case(param, "output_ramp"))
    {
      pid->output_ramp = value;
    }
    else
    {
      send_error(original, "invalid pid parameter");
      return;
    }

    send_ack(original);
    return;
  }

  if (equals_ignore_case(cmd, "LIMIT"))
  {
    char *limit_name = strtok(NULL, ",");
    float value = 0.0f;
    if (!limit_name || !parse_float(strtok(NULL, ","), &value))
    {
      send_error(original, "invalid limit command");
      return;
    }

    if (equals_ignore_case(limit_name, "voltage") || equals_ignore_case(limit_name, "volt"))
    {
      selected_motor->voltage_limit = value;
      selected_motor->PID_velocity.limit = value;
    }
    else if (equals_ignore_case(limit_name, "velocity") || equals_ignore_case(limit_name, "speed"))
    {
      selected_motor->velocity_limit = value;
      selected_motor->P_angle.limit = value;
    }
    else if (equals_ignore_case(limit_name, "angleMin") || equals_ignore_case(limit_name, "angle_min") || equals_ignore_case(limit_name, "minAngle") || equals_ignore_case(limit_name, "min_angle"))
    {
      angle_min_deg[motor_index] = clamp_angle_limit_degrees(value);
      target_angle_deg[motor_index] = clamp_angle_target_degrees(target_angle_deg[motor_index], motor_index);
    }
    else if (equals_ignore_case(limit_name, "angleMax") || equals_ignore_case(limit_name, "angle_max") || equals_ignore_case(limit_name, "maxAngle") || equals_ignore_case(limit_name, "max_angle"))
    {
      angle_max_deg[motor_index] = clamp_angle_limit_degrees(value);
      target_angle_deg[motor_index] = clamp_angle_target_degrees(target_angle_deg[motor_index], motor_index);
    }
    else if (equals_ignore_case(limit_name, "ramp") || equals_ignore_case(limit_name, "output_ramp"))
    {
      selected_motor->PID_velocity.output_ramp = value;
    }
    else
    {
      send_error(original, "invalid limit");
      return;
    }

    send_ack(original);
    return;
  }

  if (equals_ignore_case(cmd, "ENABLE"))
  {
    bool enabled = false;
    if (!parse_bool(strtok(NULL, ","), &enabled))
    {
      send_error(original, "invalid enable value");
      return;
    }

    emergency_stop = false;
    requested_enable[motor_index] = enabled;
    apply_enable_state();
    send_ack(original);
    return;
  }

  send_error(original, "unknown command");
}

void send_telemetry()
{
  uint32_t curr_millis = millis();
  if (curr_millis - prev_telemetry_millis < TELEMETRY_PERIOD_MS)
  {
    return;
  }

  Serial.print(F("{\"type\":\"tel\",\"vin\":"));
  Serial.print(get_vin_Volt(), 2);
  Serial.print(F(",\"underVoltage\":"));
  Serial.print(flag_under_voltage ? 1 : 0);
  Serial.print(F(",\"estop\":"));
  Serial.print(emergency_stop ? 1 : 0);
  Serial.print(F(",\"motors\":["));
  print_motor_json(0);
  Serial.print(',');
  print_motor_json(1);
  Serial.println(F("]}"));

  prev_telemetry_millis = curr_millis;
}

void print_motor_json(int index)
{
  BLDCMotor *selected_motor = motors[index];
  Serial.print(F("{\"index\":"));
  Serial.print(index);
  Serial.print(F(",\"name\":\""));
  Serial.print(axis_configs[index].name);
  Serial.print(F("\""));
  Serial.print(F(",\"enabled\":"));
  Serial.print(selected_motor->enabled ? 1 : 0);
  Serial.print(F(",\"requested\":"));
  Serial.print(requested_enable[index] ? 1 : 0);
  Serial.print(F(",\"mode\":\""));
  Serial.print(mode_name(selected_motor));
  Serial.print(F("\",\"target\":"));
  Serial.print(telemetry_target_for_motor(index), 4);
  Serial.print(F(",\"angle\":"));
  Serial.print(angle_rad_to_degrees_0_360(selected_motor->shaft_angle), 2);
  Serial.print(F(",\"rawAngleRad\":"));
  Serial.print(selected_motor->shaft_angle, 4);
  Serial.print(F(",\"velocity\":"));
  Serial.print(selected_motor->shaft_velocity, 4);
  Serial.print(F(",\"velocityPID\":"));
  print_pid(selected_motor->PID_velocity);
  Serial.print(F(",\"anglePID\":"));
  print_pid(selected_motor->P_angle);
  Serial.print(F(",\"limits\":{\"voltage\":"));
  Serial.print(selected_motor->voltage_limit, 4);
  Serial.print(F(",\"velocity\":"));
  Serial.print(selected_motor->velocity_limit, 4);
  Serial.print(F(",\"ramp\":"));
  Serial.print(selected_motor->PID_velocity.output_ramp, 4);
  Serial.print(F(",\"angleMin\":"));
  Serial.print(angle_min_deg[index], 2);
  Serial.print(F(",\"angleMax\":"));
  Serial.print(angle_max_deg[index], 2);
  Serial.print(F("}}"));
}

void print_pid(PIDController &pid)
{
  Serial.print(F("{\"P\":"));
  Serial.print(pid.P, 6);
  Serial.print(F(",\"I\":"));
  Serial.print(pid.I, 6);
  Serial.print(F(",\"D\":"));
  Serial.print(pid.D, 6);
  Serial.print(F(",\"limit\":"));
  Serial.print(pid.limit, 4);
  Serial.print(F(",\"output_ramp\":"));
  Serial.print(pid.output_ramp, 4);
  Serial.print('}');
}

void apply_axis_config(int index)
{
  BLDCMotor *selected_motor = motors[index];
  const AxisConfig &config = axis_configs[index];

  target_velocity_rad_s[index] = 0.0f;
  angle_min_deg[index] = clamp_angle_limit_degrees(config.angle_min_deg);
  angle_max_deg[index] = clamp_angle_limit_degrees(config.angle_max_deg);
  target_angle_deg[index] = clamp_angle_target_degrees(config.target_angle_deg, index);

  selected_motor->voltage_limit = config.voltage_limit;
  selected_motor->velocity_limit = config.velocity_limit;

  selected_motor->PID_velocity.P = config.velocity_p;
  selected_motor->PID_velocity.I = config.velocity_i;
  selected_motor->PID_velocity.D = config.velocity_d;
  selected_motor->PID_velocity.limit = config.voltage_limit;
  selected_motor->PID_velocity.output_ramp = config.velocity_ramp;

  selected_motor->P_angle.P = config.angle_p;
  selected_motor->P_angle.I = config.angle_i;
  selected_motor->P_angle.D = config.angle_d;
  selected_motor->P_angle.limit = config.velocity_limit;
  selected_motor->P_angle.output_ramp = config.angle_ramp;
}

void send_ack(const char *cmd)
{
  Serial.print(F("{\"type\":\"ack\",\"cmd\":\""));
  Serial.print(cmd);
  Serial.println(F("\"}"));
}

void send_error(const char *cmd, const char *message)
{
  Serial.print(F("{\"type\":\"err\",\"cmd\":\""));
  Serial.print(cmd ? cmd : "");
  Serial.print(F("\",\"message\":\""));
  Serial.print(message);
  Serial.println(F("\"}"));
}

BLDCMotor *select_motor(const char *token, int *motor_index)
{
  if (!token || !motor_index)
  {
    return nullptr;
  }

  char *end = nullptr;
  long index = strtol(token, &end, 10);
  if (end == token || *end != '\0')
  {
    return nullptr;
  }

  if (index < 0 || index > 1)
  {
    return nullptr;
  }

  *motor_index = (int)index;
  return motors[*motor_index];
}

bool equals_ignore_case(const char *left, const char *right)
{
  if (!left || !right)
  {
    return false;
  }

  while (*left && *right)
  {
    if (tolower((unsigned char)*left) != tolower((unsigned char)*right))
    {
      return false;
    }
    left++;
    right++;
  }

  return *left == '\0' && *right == '\0';
}

bool parse_float(const char *token, float *value)
{
  if (!token || !value)
  {
    return false;
  }

  char *end = nullptr;
  float parsed = strtof(token, &end);
  if (end == token || *end != '\0' || !isfinite(parsed))
  {
    return false;
  }

  *value = parsed;
  return true;
}

bool parse_bool(const char *token, bool *value)
{
  if (!token || !value)
  {
    return false;
  }

  if (equals_ignore_case(token, "1") || equals_ignore_case(token, "true") || equals_ignore_case(token, "on"))
  {
    *value = true;
    return true;
  }

  if (equals_ignore_case(token, "0") || equals_ignore_case(token, "false") || equals_ignore_case(token, "off"))
  {
    *value = false;
    return true;
  }

  return false;
}

const char *mode_name(BLDCMotor *selected_motor)
{
  switch (selected_motor->controller)
  {
  case MotionControlType::velocity:
    return "velocity";
  case MotionControlType::angle:
    return "angle";
  default:
    return "other";
  }
}

float angle_rad_to_degrees_0_360(float angle_rad)
{
  float normalized = fmodf(angle_rad, _2PI);
  if (normalized < 0.0f)
  {
    normalized += _2PI;
  }
  return normalized * 180.0f / _PI;
}

float degrees_to_radians(float angle_deg)
{
  return angle_deg * _PI / 180.0f;
}

float clamp_float(float value, float minimum, float maximum)
{
  if (value < minimum)
  {
    return minimum;
  }

  if (value > maximum)
  {
    return maximum;
  }

  return value;
}

float clamp_angle_limit_degrees(float angle_deg)
{
  return clamp_float(angle_deg, ANGLE_LIMIT_MIN_DEG, ANGLE_LIMIT_MAX_DEG);
}

bool angle_within_limits(float angle_deg, int motor_index)
{
  float minimum = angle_min_deg[motor_index];
  float maximum = angle_max_deg[motor_index];

  if (minimum <= maximum)
  {
    return angle_deg >= minimum && angle_deg <= maximum;
  }

  return angle_deg >= minimum || angle_deg <= maximum;
}

float circular_distance_degrees(float left, float right)
{
  float distance = fabsf(left - right);
  while (distance > ANGLE_LIMIT_MAX_DEG)
  {
    distance -= ANGLE_LIMIT_MAX_DEG;
  }

  if (distance > 180.0f)
  {
    distance = ANGLE_LIMIT_MAX_DEG - distance;
  }

  return distance;
}

float clamp_angle_target_degrees(float angle_deg, int motor_index)
{
  float clamped = clamp_angle_limit_degrees(angle_deg);
  if (angle_within_limits(clamped, motor_index))
  {
    return clamped;
  }

  float minimum = angle_min_deg[motor_index];
  float maximum = angle_max_deg[motor_index];
  if (minimum <= maximum)
  {
    return clamp_float(clamped, minimum, maximum);
  }

  return circular_distance_degrees(clamped, minimum) <= circular_distance_degrees(clamped, maximum) ? minimum : maximum;
}

float motion_target_for_motor(int motor_index)
{
  if (motors[motor_index]->controller == MotionControlType::angle)
  {
    return degrees_to_radians(clamp_angle_target_degrees(target_angle_deg[motor_index], motor_index));
  }

  return target_velocity_rad_s[motor_index];
}

float telemetry_target_for_motor(int motor_index)
{
  if (motors[motor_index]->controller == MotionControlType::angle)
  {
    return target_angle_deg[motor_index];
  }

  return target_velocity_rad_s[motor_index];
}

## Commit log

2026-05-05 按v4资料初始化项目
2026-05-06 创建了一个本地服务器，用于调试和调参PID
2026-05-21 使用网页对两个电机进行了初步PID调参，结果截图为5.21PID参数.jpg
2026-05-22 完成新一轮结构迭代和PID调参，优化了控制性能和稳定性，参数结果如5.22PID参数.jpg。
2026-05-22 网页新增一个云台控制面板：支持点击步进、按住连续移动，并显示角度可视化。
2026-10-06 docs: add README and project resources
    [GB1105带后盖.SLDASM, GB1806带后盖.SLDASM, 主体实体.SLDPRT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]
2026-10-06 docs: add gimbal motor purchase links
